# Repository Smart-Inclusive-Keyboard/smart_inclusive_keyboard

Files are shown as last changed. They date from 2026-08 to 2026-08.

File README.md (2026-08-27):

# Smart Inclusive Keyboard

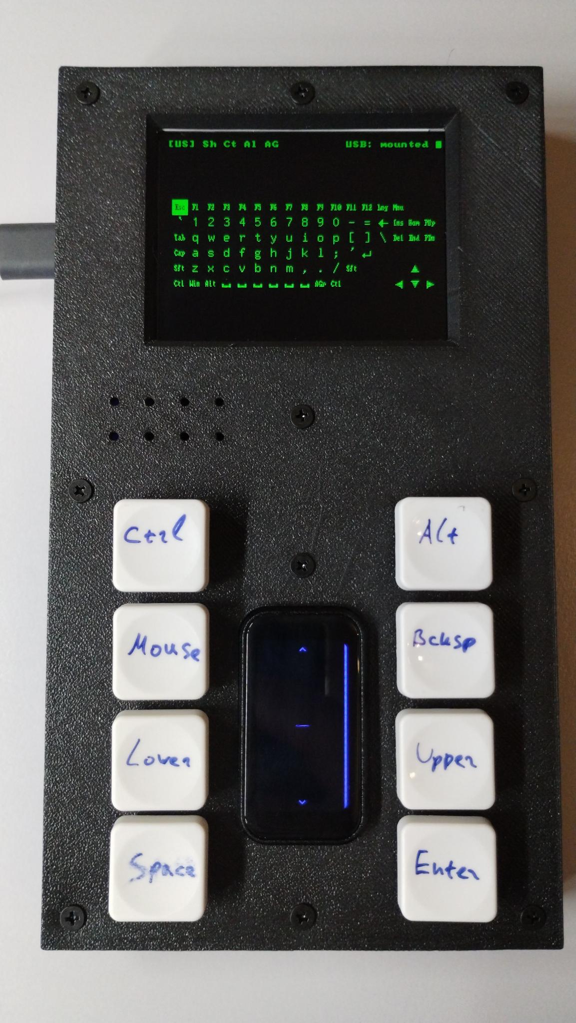
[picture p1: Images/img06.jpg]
Frontal view


This project implements a specialized keyboard for users with limited
hand function, such as those suffering from cerebral palsy.

Theh keyboard consists of 3 ESP32 units connected together:

1. The [main unit](main_unit/) is an ESP32-S3 device with an LCD
display (Freenove FNK0104A), acting as a USB keyboard and mouse
towarrd the PC host. It displays a virtual keyboard on its screen and
allows the user to navigate and select the letters that are to be sent
to the host. The attached speaker pronounces the letters that user is
navigating, so that they don't need to look at the display all the
time. The main unit provides 5v power to the two input controllers
which are connected to it via UART interfaces:

2. The [touch input controller](input_controller), an ESP32-C6 device
with a small touchscreen (Waveshare ESP32-C6-Touch-LCD-1.47). The main
input gesture that it takes from the user is the vertical finger
sliding, allowing to navigate the virtual keyboard vertically or
horizontally. Also, upon a long touch, it switches between vertical
and horizontal modes. An attached vibration motor helps indicating the
mode switch. Also, the "Mouse" button toggles the controller between
keyboard and mouse modes, so that the user can use the same sliding
motions to control the mouse cursor movements vertically or
horizontally.

3. An additional generic ESP32 device (ESP32-C3 Super Mini utilized in
this build) is used for connecting the 7 buttons, as the touch input
device does not have enough free GPIO pins. It uses the same source
code as the touch controller, only without the display and touch
functions.

See also:

1. [Bill of materials](BOM.md)

2. [Photos](Images/)

3. [Demo videos about the project
development](https://www.youtube.com/playlist?list=PLbRMZQ9npKJRurm1_IdCB4-oDc54Ccasw)

## Use of LLM

A large part of the code, especially the keyboard layouts and voice
narrator, are made with the use of Claude AI. As this is a
non-commercial and open source project, the author would never find
enough time to program it by hand.

If anyone finds any copyright infringement in the source code, the
original authors are welcome to contact me and negotiate a satisfying
solution.

## Acknowledgements

The 8x8 font is the [public-domain
font8x8](http://github.com/dhepper/font8x8). The larger 10x20 and
12x16 fonts are derived from
[Greybeard](https://github.com/flowchartsman/greybeard), a vector /
bitmap port of Uwe Waldmann's UW ttyp0 (MIT License).

## Copyright and license

This work is licensed under the MIT License.

Copyright (c) 2026 clackups@gmail.com

Fediverse: [@clackups@social.noleron.com](https://social.noleron.com/@clackups)

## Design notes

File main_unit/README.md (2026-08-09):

# Main unit for the Smart Inclusive Keyboard

ESP-IDF 6.x firmware that implements a virtual keyboard rendered on an
on-board screen, navigated with an external gamepad (receive-only
UART HID link),
that acts as a **HID keyboard + mouse** toward a host computer over
either **Bluetooth LE** (NimBLE) or **USB** (TinyUSB) -- the
transport is a build-time Kconfig choice, gated by what the chosen
ESP32 model actually supports. With PSRAM and a speaker, an
optional narrator speaks each letter as the user navigates.

## Status

The default supported board is the
**Freenove FNK0104A** (2.8" 240x320 ILI9341 SPI panel, NonTouch,
ESP32-S3 with PSRAM, on-board ES8311 codec + speaker). Additional
boards plug in via Kconfig.

## Quick start

```sh
. $IDF_PATH/export.sh
idf.py set-target esp32s3
idf.py menuconfig          # SMART KEYBOARD ->  pick board, layout, theme
idf.py build flash monitor
```

Requires **ESP-IDF v6.0 or newer** (NimBLE host, `esp_lcd`
managed components).

## Architecture

```
main/                  app entry, splash, task wiring
components/
  board/               per-board pin / capability HAL (board.h)
  display/             ILI9341 (SPI) framebuffer + draw API
  fonts/               embedded bitmap fonts (8x16, 16x32)
  theme/               color palette table (default: green on black)
  kb_layout/           keyboard layouts (US default; UA)
  keyboard_ui/         virtual-keyboard state machine + rendering
  gamepad_uart/        receive-only UART HID-report parser
  input_router/        gamepad events -> UI nav + HID dispatch
  hid/                 transport-agnostic HID facade
  ble_hid/             NimBLE composite HID backend (keyboard + mouse)
  usb_hid/             TinyUSB composite HID backend (keyboard + mouse)
  audio/               I2S WAV player (sound output is I2S-only)
  narrator/            letter-name playback (conditional)
docs/
  HARDWARE.md          per-board pinouts + UART gamepad wiring
  CONFIGURATION.md     Kconfig options + NVS overrides
  MULTI_LANG.md        how to add a new keyboard layout
```

Each subsystem is its own IDF component with a small public header
under `include/`. Hardware variants are pure Kconfig choices --
no `#ifdef` ladders outside the `board/` component.

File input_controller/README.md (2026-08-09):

# Input controller for the Smart Inclusive Keyboard

Firmware for the **Waveshare ESP32-C6-Touch-LCD-1.47** development board
that turns the capacitive touch screen into a simple gamepad-style
navigation controller. Touch gestures and dedicated GPIO buttons are
interpreted on-device and streamed as 6-byte HID gamepad reports over a
transmit-only UART to the receiver in the main unit.

A second, display-less board type is also supported for setups that only
need physical buttons (see [Board types](#board-types)).

## Overview

The board polls its AXS5106L capacitive touch controller, classifies the
touch as a long tap or a slide, samples a set of pull-up button GPIOs,
and emits the corresponding gamepad event on UART1. The 1.47" JD9853 LCD
displays a schematic navigation guide and a bright edge line that
indicates the current axis mode.

## Board types

The target board is selected under **Touch Controller -> Hardware board**
in `menuconfig`:

| Board | Display | Touch | Inputs |
|---|---|---|---|
| Waveshare ESP32-C6-Touch-LCD-1.47 | Yes | Yes | Touch gestures, buttons 0-15, mode GPIO, vibration motor |
| Generic ESP32 (no display) | No | No | Buttons 0-15 only |

The **Generic ESP32** board (`CONFIG_TC_BOARD_GENERIC_ESP32`) leaves out
the LCD, capacitive touch, gesture detection and mode GPIO entirely. It
only samples the pull-up button inputs and streams them as game
controller buttons over the transmit-only UART, so it runs on any plain
ESP32-family chip without a display.

## Hardware

Waveshare ESP32-C6-Touch-LCD-1.47 (172x320 portrait IPS):

| Function | Bus | Pins |
|---|-----|---|
| LCD (JD9853) | SPI2 | SCLK=1, MOSI=2, MISO=3, CS=14, DC=15, RST=22, BL=23 |
| Touch (AXS5106L) | I2C0 | SDA=18, SCL=19, INT=21, RST=20 (addr 0x63) |
| Gamepad output | UART1 | TX=7, 115200 8-N-1, transmit-only |
| Vibration motor | GPIO | GPIO4, active high (optional, `CONFIG_TC_HAS_VIBRATION`) |

## Button and mode inputs

Up to sixteen pull-up button inputs (buttons 0-15) plus a mode input (on
touch boards) are configured (defaults below, all configurable in
`menuconfig`). All buttons are unassigned by default; set a button GPIO
to a valid pin to enable it, or to `-1` to leave it unassigned:

| Input | Default GPIO | Action |
|---|---|---|
| Button 0..15 | -1 (unassigned) | Game controller button 0..15 while pulled low |
| Mode | 6 | Select axis output mode (touch boards only) |

Each button GPIO is active low: pulling it to ground reports the
corresponding game controller button as pressed.  A button set to `-1`
is skipped and never reports as pressed.

The **mode** GPIO is an active-low push button that toggles the axis
output mode: each press switches between **impulse** and **continuous**
mode. The button does not need to be held; the controller starts in
impulse mode. The mode GPIO exists only on boards with touch; the
generic board has no mode input.

> Note: all buttons default to unassigned (-1) and the mode GPIO to
> GPIO6; assign button GPIOs and remap the mode GPIO in `menuconfig` to
> free pins as required.

## Gesture mapping

| Gesture | Action |
|---|---|
| Slide up | Negative axis output |
| Slide down | Positive axis output |
| Long tap (>= 500 ms) | Toggle VERTICAL / HORIZONTAL mode |

Short taps are not used; on-screen gamepad buttons come exclusively from
the button GPIOs.

In **VERTICAL** mode the axis output is sent on the Y axis; in
**HORIZONTAL** mode it is sent on the X axis.

### Impulse mode (default)

A slide that spans the full length of the screen produces several axis
events; shorter slides produce proportionally fewer events (always at
least one). The number of events for a full-length slide is configurable
via `CONFIG_TC_SLIDE_FULL_EVENTS` (default 3).

The slide is tracked while the finger is held, so its direction can be
reversed without lifting: sliding up and then back down (or vice versa)
emits impulses in each direction in turn, no release required.

### Continuous mode

When continuous mode is selected, button 9 is held permanently on and
the active axis is set proportional to the sliding finger's distance
from the middle of the touch screen (fully deflected at the edges,
centred at the middle). Releasing the finger returns the axis to centre
while button 9 stays on. The long tap still switches between horizontal
and vertical movement, exactly as in impulse mode.

The finger always slides vertically (up/down); the mode only selects
which axis carries the value, so both VERTICAL and HORIZONTAL modes
respond to the same gesture.

A long tap toggles the mode as soon as `CONFIG_TC_LONG_TAP_MS` elapses
while the finger is still held down -- it does not wait for the finger to
be lifted. Once the toggle has fired, the rest of that touch (including
the eventual release) is ignored. A long tap is only recognized when the
finger stays within `CONFIG_TC_TAP_MAX_MOVE_PX` of the initial touch; if
the finger slides beyond that distance the touch is treated as a slide
and holding it still afterwards will not trigger a tap.

## Mode indicator

The screen shows two arrows and a short centre divider line (about the
width of the arrows). The current mode is shown by a bright line along
one edge of the screen:

- **VERTICAL mode** -- line along the **right** edge.
- **HORIZONTAL mode** -- line along the **top** edge.

All on-screen elements (the arrows, the centre divider and the edge
lines) share a single colour and switch together between an idle and an
active colour. In impulse mode they use `CONFIG_TC_COLOR_IMPULSE_IDLE`
while idle and switch to `CONFIG_TC_COLOR_IMPULSE_ACTIVE` as soon as a
sliding gesture is detected. In continuous mode they use the direction
indicator colour pair: `CONFIG_TC_COLOR_CONTINUOUS_IDLE` (yellow) while
idling and `CONFIG_TC_COLOR_CONTINUOUS_ACTIVE` (orange) while a sliding
gesture is detected.

## Vibration feedback

Boards with a vibration motor (`CONFIG_TC_HAS_VIBRATION`, enabled by
default on the Waveshare ESP32-C6-Touch-LCD-1.47 and driven on GPIO6 by
default) give haptic feedback for the main events:

| Event | Vibration |
|---|---|
| Axis impulse HID report issued | Very short buzz (`TC_VIB_IMPULSE_MS`) |
| Switch to VERTICAL mode | Short buzz (`TC_VIB_VERTICAL_MS`) |
| Switch to HORIZONTAL mode | Slightly longer buzz (`TC_VIB_HORIZONTAL_MS`) |
| Switch to continuous mode | Two long buzzes (`TC_VIB_LONG_MS`, gap `TC_VIB_GAP_MS`) |
| Switch to impulse mode | One long buzz (`TC_VIB_LONG_MS`) |

The motor is driven active high. All pulse durations and the vibration
motor GPIO are configurable in `menuconfig` under **Touch Controller ->
Vibration feedback**. Disable `TC_HAS_VIBRATION` to compile the feature
out entirely.

## UART gamepad report

Every event sends a 6-byte report, as defined in the main unit:

```
byte 0    : buttons 0-7   (bit n = button n pressed)
byte 1    : buttons 8-15  (bit n = button n+8 pressed)
bytes 2-3 : X axis, signed 16-bit little-endian (0 = centre)
bytes 4-5 : Y axis, signed 16-bit little-endian (0 = centre)
```

All 16 button bits are usable: buttons 0-7 occupy byte 0 and buttons
8-15 occupy byte 1.

## Configuration

Tunable options are exposed under **Touch Controller** in `menuconfig`:

| Option | Default | Description |
|---|---|---|
| `TC_HAS_VIBRATION` | y (Waveshare) | Vibration motor present |
| `TC_SCREEN_BRIGHTNESS` | 50 | Backlight brightness (percent) |
| `TC_COLOR_BACKGROUND` | 0x000000 | Background colour (0xRRGGBB) |
| `TC_COLOR_IMPULSE_IDLE` | 0x3333cc | Impulse-mode idle colour (0xRRGGBB) |
| `TC_COLOR_IMPULSE_ACTIVE` | 0x33ccff | Impulse-mode active colour (0xRRGGBB) |
| `TC_COLOR_CONTINUOUS_IDLE` | 0xffff00 | Continuous-mode idle indicator (yellow) |
| `TC_COLOR_CONTINUOUS_ACTIVE` | 0xff8000 | Continuous-mode active indicator (orange) |
| `TC_UART_TX_GPIO` | 7 | UART TX GPIO number |
| `TC_UART_BAUD` | 115200 | UART baud rate |
| `TC_BTN0_GPIO` .. `TC_BTN15_GPIO` | -1 (all unassigned) | Button 0-15 input GPIO numbers (-1 = unassigned) |
| `TC_MODE_GPIO` | 5 | Impulse/continuous mode input GPIO (touch boards) |
| `TC_SLIDE_MIN_PX` | 25 | Minimum travel to classify a slide |
| `TC_TAP_MAX_MOVE_PX` | 15 | Maximum movement for a long tap |
| `TC_LONG_TAP_MS` | 500 | Long-tap threshold (mode toggle) |
| `TC_SLIDE_FULL_EVENTS` | 3 | Axis events for a full-length slide (impulse mode) |
| `TC_VIBRATION_GPIO` | 6 | Vibration motor GPIO (active high) |
| `TC_VIB_IMPULSE_MS` | 15 | Very short buzz on each axis impulse report |
| `TC_VIB_VERTICAL_MS` | 40 | Short buzz on switching to VERTICAL mode |
| `TC_VIB_HORIZONTAL_MS` | 80 | Slightly longer buzz on switching to HORIZONTAL mode |
| `TC_VIB_LONG_MS` | 150 | Long buzz (continuous x2, impulse mode x1) |
| `TC_VIB_GAP_MS` | 80 | Gap between the two continuous-mode buzzes |

## Building and flashing

Requires ESP-IDF 6.0 or newer.

```sh
idf.py set-target esp32c6
idf.py menuconfig      # optional: adjust Touch Controller settings
idf.py build
idf.py -p <PORT> flash monitor
```

Dependencies (`espressif/esp_lcd_touch`, `espressif/esp_lvgl_port`,
`lvgl/lvgl`) are resolved automatically by the IDF component manager.

### Build presets

`CMakePresets.json` defines two configure presets that pair a build
directory with a defaults file:

- `default` -- primary Waveshare ESP32-C6 controller
  (`sdkconfig.defaults`).
- `secondary_esp32c3` -- display-less ESP32-C3 button controller
  (`sdkconfig.defaults.secondary_esp32c3`, generic board with buttons on
  UART TX GPIO10 and buttons 0-6 on GPIO0-7).

Select a preset with, for example, `idf.py -B build/secondary_esp32s3
@CMakePresets.json` or your IDE's CMake preset picker.

## Repository layout

```
main/                  application code (main.c, uart_gamepad.*)
main/Kconfig.projbuild  menuconfig options
components/             board LCD and touch drivers
sdkconfig.defaults      default build configuration (primary C6 board)
sdkconfig.defaults.secondary_esp32s3  defaults for the display-less S3 board
CMakePresets.json       build presets pairing build dirs with defaults
```

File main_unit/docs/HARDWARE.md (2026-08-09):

# Hardware

## Supported boards

### Freenove FNK0104A (2.8" ILI9341, NonTouch) (default)

| Function | GPIO | Notes |
| --- | --- | --- |
| LCD SPI CS | 10 | ILI9341 4-wire SPI panel |
| LCD SPI SCK | 12 | |
| LCD SPI MOSI (D0)  | 11 | data line written to the panel |
| LCD SPI MISO (D1)  | 13 | not required (panel is write-only) |
| LCD DC | 46 | data/command select |
| LCD RST | -1 | tied to module RST; software reset used |
| LCD BL | 45 | active HIGH, LEDC PWM |
| Gamepad 1 UART RX  | 2 | receive-only, 8-N-1, 115200 baud |
| Gamepad 2 UART RX  | 3 | receive-only, 8-N-1, 115200 baud |
| I2S MCLK / BCLK / LRCK / DOUT | 4 / 5 / 7 / 8 | on-board ES8311 codec + speaker |
| Codec I2C SDA / SCL | 16 / 15 | ES8311 codec, addr 0x18 |
| Codec PA enable | 1 | class-D amplifier enable (active-low) |

- ESP32-S3 with PSRAM (`BOARD_HAS_PSRAM`).
- Native panel resolution is 240x320 portrait; the firmware
  presents it as 320x240 landscape. The ILI9341 honours the
  MADCTL row/column-exchange bit, so the landscape rotation is
  done in hardware (no software rotation in the flush path) --
  `board_t::display.swap_xy` stays `false`.
- No touchscreen (NonTouch variant); the firmware does not include
  touchscreen support.
- On-board I2S speaker via ES8311 codec. The board selects
  `BOARD_HAS_SPEAKER` so the narrator is compiled in by default;
  the I2S / codec pins above are hard-coded in
  `components/board/src/board_freenove_fnk0104a.c`.
- The two gamepads are wired to fixed receive-only UART RX pins,
  GPIO 2 (gamepad 1) and GPIO 3 (gamepad 2). These pins are
  hard-coded in the board file (the `CONFIG_SK_GAMEPAD*_UART_RX_GPIO`
  options are ignored for this board); the UART port and baud
  still come from menuconfig.
- If the panel is physically mounted upside-down in its enclosure,
  enable `CONFIG_SK_DISPLAY_ROTATE_180` (Display menu) to flip the
  image 180 degrees at the display-controller level.

### Generic ESP32-S3 / Generic ESP32

Placeholder boards. Edit
`components/board/src/board_generic_s3.c` (or
`board_generic_esp32.c`) to fill in the pin map for your custom
wiring, then select the matching board in menuconfig.

## Gamepad wiring

The external gamepads are separate boards that stream their HID
report into this firmware over a one-way (receive-only) UART
link. Two gamepads are supported; both drive the same on-screen
keyboard. Wire each gamepad's TX line to its configured RX GPIO
(`CONFIG_SK_GAMEPAD1_UART_RX_GPIO` / `CONFIG_SK_GAMEPAD2_UART_RX_GPIO`,
GPIO 2 / 3 by default) and share a common ground. The two
gamepads must use different UART ports. Each link is 8-N-1 at
`CONFIG_SK_GAMEPAD1_UART_BAUD` / `CONFIG_SK_GAMEPAD2_UART_BAUD`
baud (115200 by default); this firmware never transmits. Set a
gamepad's RX GPIO to -1 to disable it.

The report is a fixed 6-byte frame, identical to the HID report
emitted by the companion gamepad firmware
([clackups/esp32s3_dual_foc_gp](https://github.com/clackups/esp32s3_dual_foc_gp)):

```
byte 0:  buttons 0..7  (bit i set = GP_BTN_i pressed)
byte 1:  buttons 8..9  (bits 0..1) + 6 bits padding
byte 2:  X axis, signed 16-bit LE low byte
byte 3:  X axis high byte (-32767..32767, 0 = centred, positive = right)
byte 4:  Y axis, signed 16-bit LE low byte
byte 5:  Y axis high byte (-32767..32767, 0 = centred, positive = down)
```

The firmware refers to gamepad buttons by their zero-based bit
position (`GP_BTN_0`..`GP_BTN_9`) rather than by vendor letter
names (A/B/X/Y or Cross/Circle/Square/Triangle), so the same code
works across controllers whose silkscreens disagree. Bit `i` of
the buttons bitmap triggers `GP_BTN_i`. The `input_router` mapping
is:

- `GP_BTN_0` -> press selected key (or left mouse click in mouse mode)
- `GP_BTN_1` -> Shift + selected key (or right mouse click in mouse mode)
- `GP_BTN_2` -> Space
- `GP_BTN_3` -> Enter
- `GP_BTN_4` -> Backspace
- `GP_BTN_5` -> Ctrl + selected key (like GP_BTN_0 with Ctrl held)
- `GP_BTN_6` -> AltGr + selected key (like GP_BTN_0 with right Alt held)
- `GP_BTN_7` -> unused
- `GP_BTN_8` -> unused
- `GP_BTN_9` -> on down: keyboard mode; on up: mouse mode

Sticky modifiers (Shift / Ctrl / Alt / AltGr) stay engaged until
the next character key is pressed. The keyboard layout is changed
with the on-screen **Lng** key and the colour theme / enabled
languages from the **Mnu** settings menu (both on the function-key
row, right of F12).

### UART transport

The driver installs the UART in receive-only mode (no TX / RTS /
CTS pin is driven) and reads one 6-byte frame at a time. The
analog axes are reduced to discrete D-pad directions using
`CONFIG_SK_GAMEPAD_AXIS_DEADZONE`. To adapt the wire format, edit
`gamepad_parse_report()` in
`components/gamepad_uart/src/gamepad_uart.c`.

## Power

The Freenove FNK0104A is USB-powered (5 V). `CONFIG_BOARD_HAS_BATTERY`
is not yet selected for any shipping board -- when it is,
`board_t.battery_adc_channel` gates the on-screen battery indicator.

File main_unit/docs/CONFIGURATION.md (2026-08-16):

# Configuration

All build-time options live under
**SMART KEYBOARD** in `idf.py menuconfig`.

## Board selection

`SK_BOARD_*` -- exactly one. The default is
`SK_BOARD_FREENOVE_FNK0104A` (Freenove 2.8" ILI9341, NonTouch).
Selecting a board automatically
"selects" the capability symbols that gate optional components:

| Symbol | Meaning |
| --- | --- |
| `BOARD_HAS_PSRAM` | Component code may allocate from PSRAM |
| `BOARD_HAS_DISPLAY` | Some panel driver is configured |
| `BOARD_HAS_DISPLAY_ILI9341`  | Build the ILI9341 SPI backend |
| `BOARD_HAS_SPEAKER` | I2S DAC wired -> compile in audio + |
| | narrator |
| `BOARD_HAS_BATTERY` | VBAT exposed -> battery indicator |

The Audio / Narrator menu is **hidden** unless `BOARD_HAS_PSRAM`
and `BOARD_HAS_SPEAKER` are both set, because narration requires
both to be useful.

## Display

`SK_DISPLAY_BACKLIGHT_PERCENT` (0..100) sets the panel backlight
brightness applied at boot, as a percentage of full brightness.
Boards with a controllable (LEDC PWM) backlight honour it; boards
without one ignore it. The default is tuned per board: 50% for the
Freenove FNK0104A.

`SK_DISPLAY_ROTATE_180` flips the panel image 180 degrees (both
axes mirrored) at the display-controller level. Useful when the
panel is physically mounted upside-down in its enclosure, e.g. the
Freenove FNK0104A.

## Gamepad transport

The external gamepads are separate boards that stream their HID
report into this firmware over a one-way (receive-only) UART
link (8-N-1). This firmware never transmits. Two gamepads are
supported; both feed the same `gamepad_event_t` queue and drive
the same on-screen keyboard. The 6-byte report format and queue
feed a transport-agnostic `input_router`.

| Option | Default | Range |
| --- | --- | --- |
| `SK_GAMEPAD_AXIS_DEADZONE` | 8000 | 0..32767 |
| `SK_GAMEPAD1_UART_PORT` | 1 | 1..2 (UART1 / UART2) |
| `SK_GAMEPAD1_UART_RX_GPIO` | 21 | any GPIO, -1 = off |
| `SK_GAMEPAD1_UART_BAUD` | 115200  | any baud rate |
| `SK_GAMEPAD2_UART_PORT` | 2 | 1..2 (UART1 / UART2) |
| `SK_GAMEPAD2_UART_RX_GPIO` | 38 | any GPIO, -1 = off |
| `SK_GAMEPAD2_UART_BAUD` | 115200  | any baud rate |

Each RX pin is connected to a gamepad's TX line; no TX / RTS /
CTS pin is driven. The two gamepads must use different UART ports.
Set a gamepad's `*_UART_RX_GPIO` to -1 to disable it.

> **Note:** On the Freenove FNK0104A board the gamepad RX pins are
> hard-coded to GPIO 2 (gamepad 1) and GPIO 3 (gamepad 2) in the
> board file, so the `SK_GAMEPAD*_UART_RX_GPIO` options above have
> no effect for that board. The UART port and baud options still
> apply.
`SK_GAMEPAD_AXIS_DEADZONE` is shared by both gamepads and applied
to the signed 16-bit analog axes carried in the report. See
[HARDWARE.md](HARDWARE.md) for the wire format and button map.

## HID transport

The firmware acts as a HID peripheral over either Bluetooth LE or
USB. The transport is selected at build time via
`SK_HID_TRANSPORT`; each option is only offered when the target
SoC actually has the corresponding controller
(`SOC_BLE_SUPPORTED` / `SOC_USB_OTG_SUPPORTED`).

| Option | Targets | Backend |
| --- | --- | --- |
| `SK_HID_TRANSPORT_BLE`  | classic ESP32, S3 | NimBLE GATT HID |
| `SK_HID_TRANSPORT_USB`  | ESP32-S2, S3, P4  | TinyUSB composite HID |

The classic ESP32 only exposes the BLE option; ESP32-S2 only the
USB option; ESP32-S3 lets you pick either.

## BLE HID

Only visible when `SK_HID_TRANSPORT_BLE` is selected.

| Option | Default | Purpose |
| --- | --- | --- |
| `SK_BLE_DEVICE_NAME` | `SmartKeyboard`| advertised local name |
| `SK_BLE_MANUFACTURER` | `clackups` | shown in some host UIs |
| `SK_BLE_BOND_ON_PAIR` | y | persist bonds to NVS |

## USB HID

Only visible when `SK_HID_TRANSPORT_USB` is selected.

| Option | Default | Purpose |
| --- | --- | --- |
| `SK_USB_MANUFACTURER` | `clackups` | USB iManufacturer string |
| `SK_USB_PRODUCT` | `SmartKeyboard`| USB iProduct string |
| `SK_USB_SERIAL` | `000001` | USB iSerial string |

When building a pure-USB image you can also disable the Bluetooth
stack in `menuconfig > Component config > Bluetooth` to reclaim
the ~60 KB it occupies in flash + ~30 KB in RAM.

## Keyboard layout

`SK_LAYOUT_DEFAULT` is the compile-time default. The active layout
is **not** persisted to NVS: the device always boots with the first
*available* (Kconfig-activated) language. The active layout is
bound to the on-screen **Lng** key (right of F12), which rotates
through the *enabled* languages only (see the settings menu below).
Both US and Ukrainian (UA) are full layouts. The Ukrainian layout
renders the real Cyrillic letters on the keys (upper-cased while
Shift is held), using the Cyrillic glyphs embedded in the 10x20 UI
font.

### Enabled languages

The **Enabled languages** Kconfig switches decide which layouts are
*available* on the device. Only available layouts are offered in the
settings menu and take part in the Lng rotation:

| Option | Default | Layout |
| --- | --- | --- |
| `SK_LANG_ENABLE_US` | y | US English |
| `SK_LANG_ENABLE_UA` | y | Ukrainian (UA) |

Layouts not activated here never appear in the settings menu. The
enabled set among the available layouts can be changed at runtime
from the settings menu, but is not persisted across reboots.
`SK_LANG_ENABLE_UA` also controls whether the Ukrainian narrator
clips (`wav/ua_*.wav`) are embedded into the firmware image.

### Host layout-switch hotkey

When the device's active layout changes, the firmware emits
`Ctrl+Shift+<digit>` so a host configured with matching
input-language hotkeys switches along with it. Each language's
digit is configurable under **Host layout-switch hotkey**; `0`
disables the report for that language:

| Option | Default | Sends |
| --- | --- | --- |
| `SK_LAYOUT_SWITCH_DIGIT_US` | 1 | Ctrl+Shift+1 |
| `SK_LAYOUT_SWITCH_DIGIT_UA` | 4 | Ctrl+Shift+4 |

## Theme

Same model as the layout: a Kconfig default that can be changed
at runtime from the settings menu (`keyboard_ui_cycle_theme()`).
Five built-ins ship: `green_on_black` (default),
`darkgreen_on_black`, `white_on_black`, `black_on_white`,
`default`.

## Settings menu

The on-screen **Mnu** key (right of F12) opens a modal,
gamepad-navigated settings menu. While it is open the keyboard is
replaced by the menu and the gamepad routes here: Up/Down move the
selection, Left/Right change the highlighted value, and the action
button (`GP_BTN_0`) activates it. The menu lets the user pick the
colour theme, set the **mouse pointer speed** (7 levels, slow to
fast), toggle **navigation rollover** and toggle which of the
*available* (Kconfig-activated) languages take part in the Lng
rotation. Languages not activated in Kconfig are not listed. At
least one language is always enabled and the active language can
never be disabled. Theme, mouse-speed and navigation-rollover
choices persist to NVS; the language selection does not.

Navigation rollover (`Nav rollover: ON/off`, default **off**)
controls what happens when the selection cursor is moved past the
edge of the on-screen key grid. When disabled (the default), the
cursor clamps at the edge row/column. When enabled, moving past an
edge wraps the selection around to the opposite edge in that same
axis (e.g. moving up from the top row selects the bottom row of the
same column).

## Gamepad buttons

The external gamepad's numbered buttons map to fixed actions
(`components/input_router`):

| Button | Keyboard mode | Mouse mode |
| --- | --- | --- |
| `GP_BTN_0` | press selected key | left click |
| `GP_BTN_1` | Shift + selected key | right click |
| `GP_BTN_2` | Space | Space |
| `GP_BTN_3` | Enter | Enter |
| `GP_BTN_4` | Backspace | Backspace |
| `GP_BTN_5` | Ctrl + selected key | left click |
| `GP_BTN_6` | AltGr + selected key | left click |
| `GP_BTN_7` | unused | unused |
| `GP_BTN_8` | unused | unused |
| `GP_BTN_9` | down: mouse mode; up: keyboard mode |

The D-pad / analog stick moves the selection cursor (keyboard
mode) or the menu selection (settings menu). In **mouse mode** the
analog axes drive the pointer **proportionally**: the further the
stick is pushed past the dead-zone, the faster the pointer moves,
scaled by the Mouse-speed level chosen in the settings menu.
`GP_BTN_5` / `GP_BTN_6` act like `GP_BTN_0` but momentarily
hold Ctrl / AltGr for that single keypress. Shift / Ctrl / Alt /
AltGr toggled via the on-screen modifier keys are **sticky**: they
hold the modifier until the next character key is pressed.

## Audio / narrator (conditional)

| Option | Default | Purpose |
| --- | --- | --- |
| `NARRATOR_ENABLE` | y | speak each key as it is sent |
| `AUDIO_I2S_PORT` | 0 | I2S port (0 or 1) |
| `AUDIO_I2S_BCLK_GPIO` | 5 | |
| `AUDIO_I2S_LRCK_GPIO` | 6 | |
| `AUDIO_I2S_DOUT_GPIO` | 7 | |
| `AUDIO_VOLUME` | 70 | 0..100, applied digitally |

The narrator pronounces the letter or symbol that a gamepad
action sends, taking the current Shift state into account. The
Ukrainian layout ships its own clip set so the spoken name matches
the Cyrillic character the host receives, not the ASCII
transliteration drawn on screen.

Sound output is **always** I2S -- there is no PWM / internal-DAC
fallback. On boards without `BOARD_HAS_SPEAKER` selected the
audio + narrator components compile to no-op stubs so calls from
`input_router` are free.

## NVS overrides

Runtime preferences live under the `sk_ui` NVS namespace:

| Key | Type | Set by |
| --- | ---- | --- |
| `theme` | str  | `keyboard_ui_cycle_theme()` |

The active language and the enabled-language set are intentionally
not persisted: the device always boots with the first available
(Kconfig-activated) layout.

To reset to the Kconfig defaults, erase the namespace from a
serial console or wipe NVS with `idf.py erase-flash`.

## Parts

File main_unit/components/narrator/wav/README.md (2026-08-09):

# Narrator assets

This directory holds WAV files embedded into the firmware at
build time via `EMBED_FILES` (see
`components/narrator/CMakeLists.txt`). The narrator component is
**only** compiled in when the selected board has both PSRAM and
a speaker and `CONFIG_NARRATOR_ENABLE` is set; otherwise the
embed list is skipped entirely.

## Where do the WAVs come from?

They are taken verbatim from the upstream
[clackups/smart-keyboard](https://github.com/clackups/smart-keyboard)
project's `audio/` folder (MIT-licensed, same as this firmware).
The letter / digit clips are the US-English set
(`us_<letter>.wav` / `us_<digit>.wav` upstream), renamed to drop
the `us_` prefix so they match the symbol names the narrator
declares. `esc.wav` upstream is imported as `escape.wav`. The
narrator expects the following filenames:

```
a.wav, b.wav, ..., z.wav
0.wav, 1.wav, ..., 9.wav
space.wav, enter.wav, backspace.wav, tab.wav, escape.wav
shift.wav, ctrl.wav, alt.wav, altgr.wav, capslock.wav
apostrophe.wav, backslash.wav, backtick.wav, comma.wav,
equals.wav, lbracket.wav, minus.wav, period.wav,
rbracket.wav, semicolon.wav, slash.wav
f1.wav .. f12.wav
insert.wav, home.wav, pageup.wav,
delete.wav, end.wav, pagedown.wav,
up.wav, down.wav, left.wav, right.wav
```

Every cell of the on-screen US layout has a matching clip
except the "Win" / "Cmd" modifier (no upstream recording);
that key narrates as silence.

### Shifted number-row symbols

The number row's Shift glyphs (`~ ! @ # $ % ^ & * ( ) _ +`) are
not separate HID usages -- Shift+1 still sends
`HID_USAGE_1`, only the host-side glyph changes -- so the
narrator can't derive their spoken name from the HID usage
alone. `layout_us.c` names an explicit narrator clip token per
key (see the `KSH` macro) for the following language-neutral
clips, spoken in place of the unshifted digit / mark while
Shift is held:

```
tilde.wav, exclamation.wav, at.wav, hash.wav, dollar.wav,
percent.wav, caret.wav, ampersand.wav, asterisk.wav,
lparen.wav, rparen.wav, underscore.wav, plus.wav
```

These were synthesized with `espeak-ng` (`espeak-ng -v en-us -s
150 -w <name>.wav "<word>"`) at the same PCM16/22050Hz mono
format as the rest of the pack; replace with recordings from the
upstream pack if/when it adds them.

## Format

Standard RIFF/WAVE, **PCM 16-bit mono, 22050 Hz**. The I2S
driver re-clocks to the file's reported sample rate, so other
rates work too, but 22050 / 16-bit is what the upstream pack
uses and what the audio buffer sizes in `components/audio/` are
tuned for.

## License

MIT, inherited from the upstream project. See its `LICENSE`
file for the exact text.

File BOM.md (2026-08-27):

# Smart Inclusive Keyboard - Bill of materials

Electronic components:

1. 1pc [Freenove FNK0104A
board](https://docs.freenove.com/projects/fnk0104/en/latest/fnk0104/codes/MAIN/Freenove_ESP32S3_Display.html)
(2.8" LCD, no touch, with speaker)

2. 1pc [Waveshare ESP32-C6-Touch-LCD-1.47](https://docs.waveshare.com/ESP32-C6-Touch-LCD-1.47)

3. 1pc [ESP32-C3 Super Mini](https://www.espboards.dev/esp32/esp32-c3-super-mini/)

4. 1pc [Vibration Motor
Module](https://easyelecmodule.com/vibration-motor-module/)

Assembly:

1. Top cover: 10pc [M2.5 x 12mm Hexagonal Male/Female Standoffs](https://www.vital-parts.co.uk/threaded-hex-standoffs-male-female/11245-hmf-m25-12-s5-npb), 10pc M3.5 x 5mmPhillips Ultra Thin Flat Head Screws, 10pc M2.5 nuts.

2. Freenove FNK0104A: 4pc M3 x 6mm Hexagonal Female/Female Standoffs, 4pc M3 x5mm screws, 4pc M3 x 6mm screws.

3. The speaker has an adhesive surface and sticks to the bottom plate.

4. Waveshare ESP32-C6-Touch-LCD-1.47: 4pc M2 x 8mm Male/Female Standoffs, 4pc M2 x 6mm screws.

5. Vibration Motor: 2pc M3 x 10mm screws, 2pc M3 nuts.

Other components:

1. 8pc low-profile MX keyboard switchhes

2. 8pc low-profile keycaps

3. 5pc 12x6mm self-adhesive silicone bumpers

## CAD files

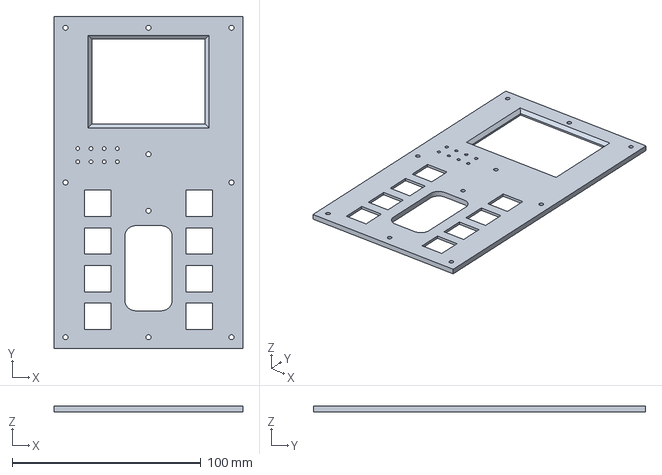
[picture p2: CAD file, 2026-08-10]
3D_Prints/body_top-Body.3mf
100.0 x 176.0 x 3.00 mm

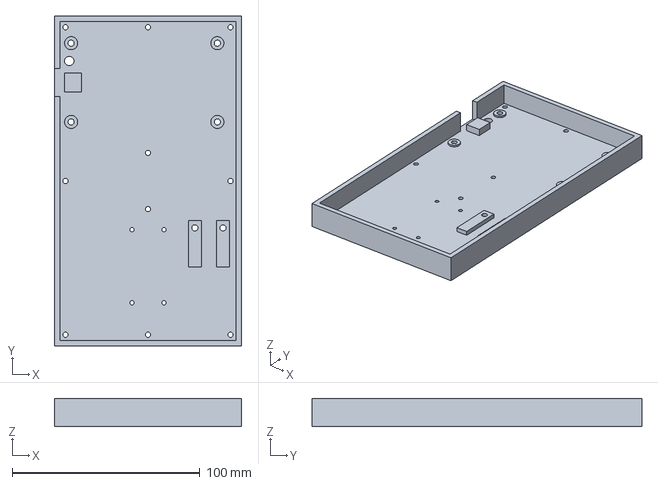
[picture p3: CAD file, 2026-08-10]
3D_Prints/body_bottom-Body.3mf
100.0 x 176.0 x 15.0 mm

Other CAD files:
3D_Prints/body_bottom.FCStd
3D_Prints/body_top.FCStd

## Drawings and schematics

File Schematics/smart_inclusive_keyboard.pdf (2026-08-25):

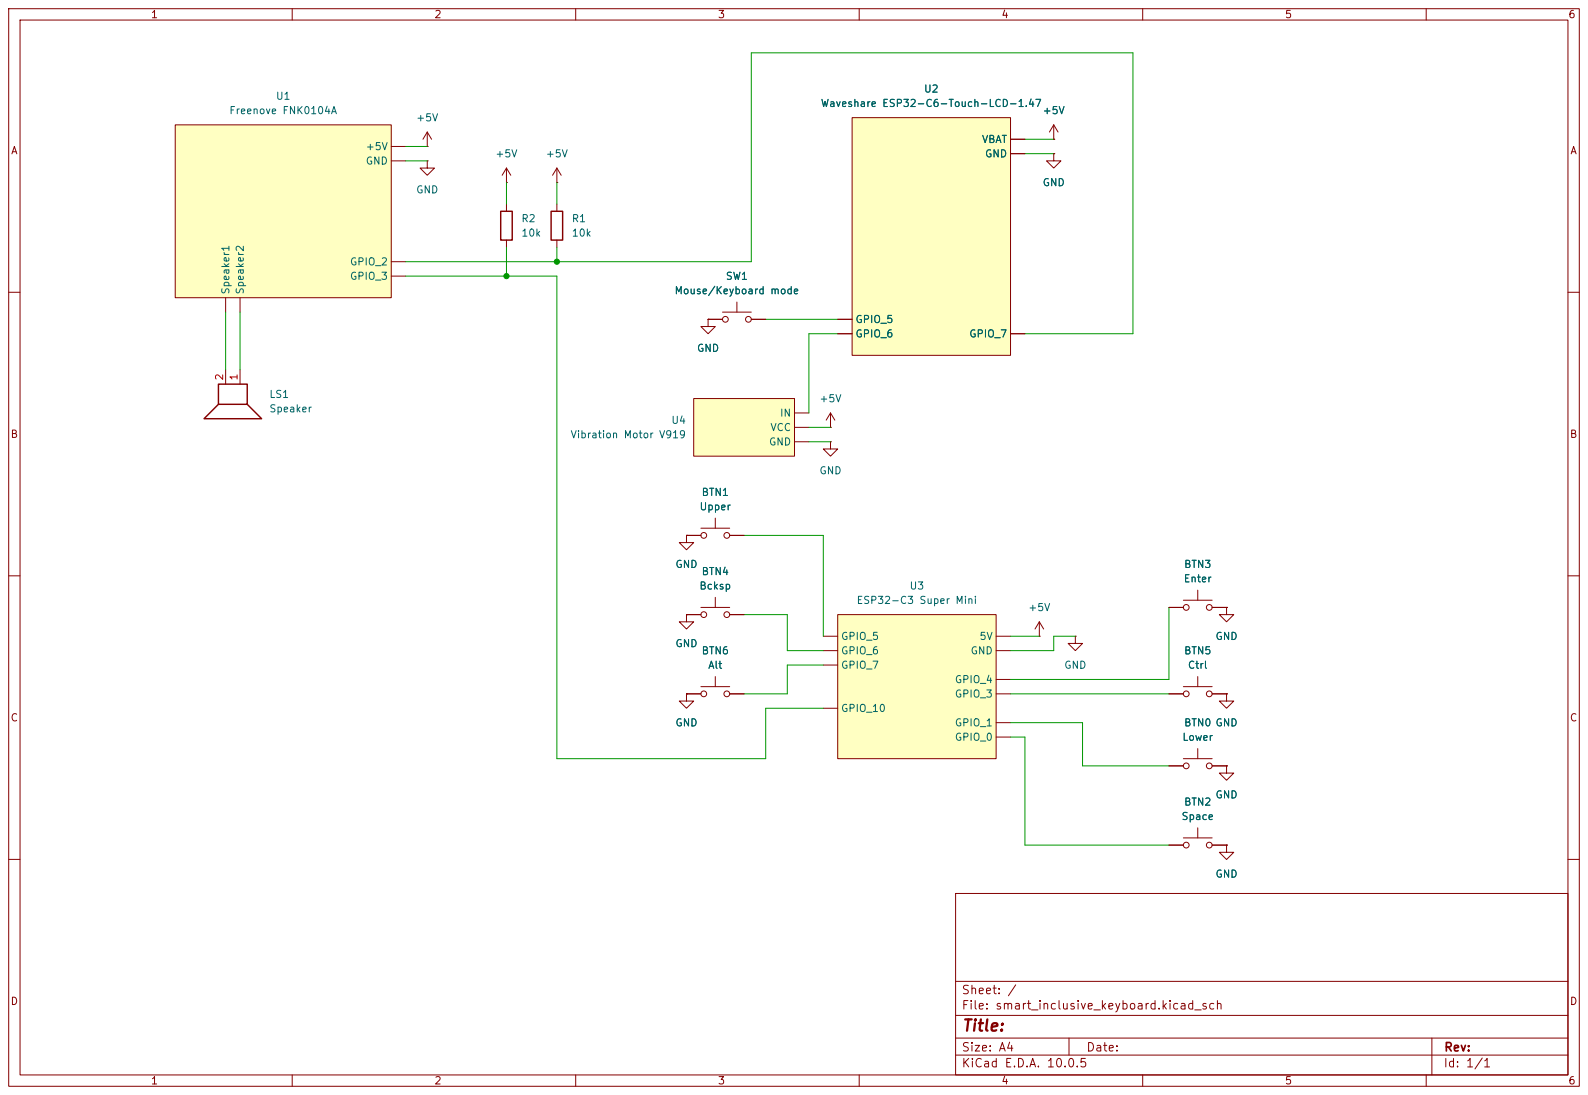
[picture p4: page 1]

GPIO_7 U2 Waveshare ESP32-C6-Touch-LCD-1.47 BTN4 Bcksp GND

Enter GND +5V U2 Waveshare ESP32-C6-Touch-LCD-1.47 GPIO_5 GPIO_6

Size: A4 | Rev:
KiCad E.D.A. 10.0.5 | Id: 1/1

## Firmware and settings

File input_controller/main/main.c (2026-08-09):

/*
 * main.c -- ESP32 Touch Controller
 *
 * Reads capacitive touch from an AXS5106L controller, interprets the
 * gestures, and sends 6-byte HID gamepad reports over a transmit-only
 * UART to an esp32s3_smart_keyboard receiver.
 *
 * Two board types are supported, selected in menuconfig:
 *   - Waveshare ESP32-C6-Touch-LCD-1.47 (display + touch, described
 *     below).  Selects CONFIG_TC_HAS_DISPLAY and CONFIG_TC_HAS_TOUCH.
 *   - Generic ESP32 (CONFIG_TC_BOARD_GENERIC_ESP32): no display and no
 *     touch; only the pull-up button inputs and the UART gamepad output
 *     are built.  Neither capability flag is set, so all LCD/touch and
 *     gesture code below is compiled out.
 *
 * Hardware (Waveshare ESP32-C6-Touch-LCD-1.47, verified):
 *   LCD  JD9853  SPI2   SCLK=1 MOSI=2 MISO=3  CS=14 DC=15 RST=22 BL=23
 *                172x320 portrait, column gap=34, colour-inversion on
 *   Touch AXS5106L  I2C0  SDA=18 SCL=19 INT=21 RST=20  addr=0x63
 *   UART  TX=GPIO7  115200 8-N-1  (gamepad HID output)
 *   Vibration motor  GPIO4  (active high, CONFIG_TC_HAS_VIBRATION)
 *
 * Button/mode inputs (configurable, pull-up, active low):
 *   GPIO for buttons 0-15  generate game controller buttons 0-15
 *   Mode GPIO              each press toggles impulse <-> continuous mode
 *                          (touch boards only)
 *
 * Optional vibration feedback (CONFIG_TC_HAS_VIBRATION) pulses a motor
 * GPIO to acknowledge events: a very short buzz on every axis impulse HID
 * report, a short buzz on switching to VERTICAL and a slightly longer one
 * on switching to HORIZONTAL, two long buzzes on switching to continuous
 * mode and one long buzz on switching to impulse mode.  All durations are
 * configurable (see Kconfig).
 *
 * Gesture -> HID mapping
 *   Slide up        negative axis impulse (impulse mode) or proportional
 *                   axis (continuous mode)
 *   Slide down      positive axis impulse (impulse mode) or proportional
 *                   axis (continuous mode)
 *   Long tap (>=TC_LONG_TAP_MS) toggle VERTICAL / HORIZONTAL mode
 *                          (fires as soon as the threshold elapses,
 *                          without waiting for the finger to lift)
 *
 * In impulse mode a slide spanning the full length of the screen emits
 * several axis impulse events (CONFIG_TC_SLIDE_FULL_EVENTS, default 3);
 * shorter slides emit proportionally fewer events.  The slide is tracked
 * while the finger is held, so its direction can be reversed without
 * lifting: turning back on the slide emits impulses in the new direction.
 *
 * The finger always slides vertically (up/down).  In continuous mode
 * button 9 is held permanently on and the active axis is set proportional
 * to the sliding finger's distance from the middle of the touch screen;
 * the long tap switches the active axis just as in impulse mode.  Both
 * VERTICAL and HORIZONTAL modes react to the same up/down gesture.
 *
 * In VERTICAL mode the axis output is sent on the Y axis; in HORIZONTAL
 * mode it is sent on the X axis.
 *
 * The screen shows a schematic navigation guide with two arrows and a
 * short centre divider line.  The current mode is indicated by a bright
 * edge line: along the right edge in VERTICAL mode and along the top edge
 * in HORIZONTAL mode.  All on-screen elements (arrows, divider and edge
 * lines) share one colour and switch together between an idle and an
 * active colour: in impulse mode the idle CONFIG_TC_COLOR_IMPULSE_IDLE
 * and the active CONFIG_TC_COLOR_IMPULSE_ACTIVE (applied as soon as a
 * slide is detected), and in continuous mode the indicator colour pair
 * (idle CONFIG_TC_COLOR_CONTINUOUS_IDLE, active
 * CONFIG_TC_COLOR_CONTINUOUS_ACTIVE).  Backlight brightness and the
 * interface colours are configurable (see Kconfig).
 */

#include <string.h>
#include <stdio.h>
#include "freertos/FreeRTOS.h"
#include "freertos/task.h"
#include "freertos/queue.h"
#include "esp_log.h"
#include "esp_timer.h"
#include "esp_err.h"
#include "driver/gpio.h"

#include "sdkconfig.h"

#if CONFIG_TC_HAS_DISPLAY
#include "driver/spi_master.h"
#include "driver/ledc.h"

#include "esp_lcd_panel_io.h"
#include "esp_lcd_panel_vendor.h"
#include "esp_lcd_panel_ops.h"
#include "esp_lcd_jd9853.h"

#include "esp_lvgl_port.h"
#include "lvgl.h"
#endif /* CONFIG_TC_HAS_DISPLAY */

#if CONFIG_TC_HAS_TOUCH
#include "driver/i2c_master.h"

#include "esp_lcd_touch.h"
#include "esp_lcd_touch_axs5106.h"
#endif /* CONFIG_TC_HAS_TOUCH */

#include "uart_gamepad.h"

static const char *TAG = "tc";

/* ---------------------------------------------------------------------
 * Board-specific pin definitions
 * --------------------------------------------------------------------- */
#ifdef CONFIG_TC_BOARD_WAVESHARE_C6_TOUCH_LCD_147

/* LCD SPI (SPI2) */
#define LCD_SCLK         GPIO_NUM_1
#define LCD_MOSI         GPIO_NUM_2
#define LCD_MISO         GPIO_NUM_3
#define LCD_CS           GPIO_NUM_14
#define LCD_DC           GPIO_NUM_15
#define LCD_RST          GPIO_NUM_22
#define LCD_BL           GPIO_NUM_23
#define LCD_PIXEL_CLK_HZ (80 * 1000 * 1000)
#define LCD_H_RES        172
#define LCD_V_RES        320
#define LCD_COL_GAP      34   /* JD9853 x-offset at rotation 0 */

/* Touch I2C (I2C0) */
#define TP_SDA           GPIO_NUM_18
#define TP_SCL           GPIO_NUM_19
#define TP_INT           GPIO_NUM_21
#define TP_RST           GPIO_NUM_20

/* Backlight PWM */
#define BL_LEDC_TIMER    LEDC_TIMER_0
#define BL_LEDC_MODE     LEDC_LOW_SPEED_MODE
#define BL_LEDC_CH       LEDC_CHANNEL_0
#define BL_LEDC_DUTY_RES LEDC_TIMER_10_BIT
#define BL_LEDC_FREQ_HZ  5000

#endif /* CONFIG_TC_BOARD_WAVESHARE_C6_TOUCH_LCD_147 */

/* ---------------------------------------------------------------------
 * Application constants
 * --------------------------------------------------------------------- */
#define INPUT_POLL_MS   20    /* button / touch polling interval      */

/* Button input GPIOs (pull-up, active low, from Kconfig). */
#define BTN_GPIO_COUNT  16

/* Button index that is held on permanently while in continuous mode. */
#define CONTINUOUS_BTN  9

#if CONFIG_TC_HAS_DISPLAY
#define DRAW_BUF_LINES  50    /* LVGL DMA draw buffer height in lines */

/* Interface colours (24-bit 0xRRGGBB, from Kconfig). */
#define COLOR_BG        lv_color_hex(CONFIG_TC_COLOR_BACKGROUND)
#define COLOR_FG        lv_color_hex(CONFIG_TC_COLOR_IMPULSE_IDLE)
#define COLOR_HL        lv_color_hex(CONFIG_TC_COLOR_IMPULSE_ACTIVE)
#define COLOR_CONT_IDLE   lv_color_hex(CONFIG_TC_COLOR_CONTINUOUS_IDLE)
#define COLOR_CONT_ACTIVE lv_color_hex(CONFIG_TC_COLOR_CONTINUOUS_ACTIVE)

/* vertical/horizontal indicator line along the edge */
#define EDGE_INDICATOR_THICKNESS 4

/* Width of the short centre divider line -- approximately the width of
 * the up/down arrow glyphs it sits between. */
#define DIVIDER_WIDTH   24
#endif /* CONFIG_TC_HAS_DISPLAY */

#if CONFIG_TC_HAS_TOUCH
#define IMPULSE_MS      100   /* axis impulse duration                */

#define SLIDE_MIN_PX    CONFIG_TC_SLIDE_MIN_PX
#define TAP_MAX_MOVE_PX CONFIG_TC_TAP_MAX_MOVE_PX
#define LONG_TAP_MS     CONFIG_TC_LONG_TAP_MS
#define SLIDE_FULL_EVENTS CONFIG_TC_SLIDE_FULL_EVENTS

#define MODE_GPIO       CONFIG_TC_MODE_GPIO
#endif /* CONFIG_TC_HAS_TOUCH */

#if CONFIG_TC_HAS_VIBRATION
/* Vibration motor GPIO (active high) and feedback pulse durations. */
#define VIB_GPIO          CONFIG_TC_VIBRATION_GPIO
#define VIB_IMPULSE_MS    CONFIG_TC_VIB_IMPULSE_MS    /* very short */
#define VIB_VERTICAL_MS   CONFIG_TC_VIB_VERTICAL_MS   /* short      */
#define VIB_HORIZONTAL_MS CONFIG_TC_VIB_HORIZONTAL_MS /* longer     */
#define VIB_LONG_MS       CONFIG_TC_VIB_LONG_MS       /* long       */
#define VIB_GAP_MS        CONFIG_TC_VIB_GAP_MS        /* pulse gap  */
#else
/* Fallback durations so the vibration_trigger() no-op call sites compile
 * unchanged when no vibration motor is present. */
#define VIB_IMPULSE_MS    0
#define VIB_VERTICAL_MS   0
#define VIB_HORIZONTAL_MS 0
#define VIB_LONG_MS       0
#define VIB_GAP_MS        0
#endif /* CONFIG_TC_HAS_VIBRATION */

typedef enum {
    MODE_VERTICAL,
    MODE_HORIZONTAL,
} tc_mode_t;

/* Axis output mode, selected by the mode GPIO. */
typedef enum {
    OUTPUT_IMPULSE,
    OUTPUT_CONTINUOUS,
} tc_output_mode_t;

/* ---------------------------------------------------------------------
 * Module-level state
 * --------------------------------------------------------------------- */
#if CONFIG_TC_HAS_DISPLAY
static esp_lcd_panel_io_handle_t s_io_handle;
static esp_lcd_panel_handle_t    s_panel;
static lv_disp_t                *s_disp;
static lv_obj_t                 *s_line_right;  /* shown in VERTICAL mode   */
static lv_obj_t                 *s_line_top;    /* shown in HORIZONTAL mode */
static lv_obj_t                 *s_lbl_up;      /* up arrow                 */
static lv_obj_t                 *s_lbl_dn;      /* down arrow               */
static lv_obj_t                 *s_divider;     /* short centre line        */

/* Backlight PWM full-scale duty (2^BL_LEDC_DUTY_RES - 1), computed once
 * in hw_lcd_init(), used to scale a 0..100 percent request. */
static uint32_t s_bl_max_duty;
#endif /* CONFIG_TC_HAS_DISPLAY */
#if CONFIG_TC_HAS_TOUCH
static esp_lcd_touch_handle_t    s_touch;
#endif /* CONFIG_TC_HAS_TOUCH */
#if CONFIG_TC_HAS_DISPLAY || CONFIG_TC_HAS_TOUCH
static volatile tc_mode_t        s_mode = MODE_VERTICAL;
#endif
static volatile tc_output_mode_t s_output_mode = OUTPUT_IMPULSE;

/* Button GPIOs (buttons 0-15; -1 = unassigned). */
static const int s_btn_gpios[BTN_GPIO_COUNT] = {
    CONFIG_TC_BTN0_GPIO,  CONFIG_TC_BTN1_GPIO,  CONFIG_TC_BTN2_GPIO,
    CONFIG_TC_BTN3_GPIO,  CONFIG_TC_BTN4_GPIO,  CONFIG_TC_BTN5_GPIO,
    CONFIG_TC_BTN6_GPIO,  CONFIG_TC_BTN7_GPIO,  CONFIG_TC_BTN8_GPIO,
    CONFIG_TC_BTN9_GPIO,  CONFIG_TC_BTN10_GPIO, CONFIG_TC_BTN11_GPIO,
    CONFIG_TC_BTN12_GPIO, CONFIG_TC_BTN13_GPIO, CONFIG_TC_BTN14_GPIO,
    CONFIG_TC_BTN15_GPIO,
};

/* Latest button bitmask read from the button GPIOs (buttons 0-15). */
static volatile uint16_t s_gpio_buttons;

/* Latest axis values pushed to the gamepad report. */
static volatile int16_t s_axis_x;
static volatile int16_t s_axis_y;

/* ---------------------------------------------------------------------
 * Hardware initialisation
 * --------------------------------------------------------------------- */
#if CONFIG_TC_HAS_DISPLAY
static void hw_lcd_init(void)
{
    /* SPI bus */
    const spi_bus_config_t buscfg = {
        .sclk_io_num     = LCD_SCLK,
        .mosi_io_num     = LCD_MOSI,
        .miso_io_num     = LCD_MISO,
        .quadhd_io_num   = -1,
        .quadwp_io_num   = -1,
        .max_transfer_sz = LCD_H_RES * DRAW_BUF_LINES * sizeof(uint16_t),
    };
    ESP_ERROR_CHECK(spi_bus_initialize(SPI2_HOST, &buscfg, SPI_DMA_CH_AUTO));

    /* Panel IO */
    esp_lcd_panel_io_spi_config_t io_cfg =
        JD9853_PANEL_IO_SPI_CONFIG(LCD_CS, LCD_DC, NULL, NULL);
    io_cfg.pclk_hz = LCD_PIXEL_CLK_HZ;
    ESP_ERROR_CHECK(esp_lcd_new_panel_io_spi(
        (esp_lcd_spi_bus_handle_t)SPI2_HOST, &io_cfg, &s_io_handle));

    /* Panel */
    const esp_lcd_panel_dev_config_t panel_cfg = {
        .reset_gpio_num = LCD_RST,
        .rgb_ele_order  = LCD_RGB_ELEMENT_ORDER_RGB,
        .bits_per_pixel = 16,
    };
    ESP_ERROR_CHECK(esp_lcd_new_panel_jd9853(s_io_handle, &panel_cfg, &s_panel));
    ESP_ERROR_CHECK(esp_lcd_panel_reset(s_panel));
    ESP_ERROR_CHECK(esp_lcd_panel_init(s_panel));
    ESP_ERROR_CHECK(esp_lcd_panel_invert_color(s_panel, true));
    ESP_ERROR_CHECK(esp_lcd_panel_set_gap(s_panel, LCD_COL_GAP, 0));
    ESP_ERROR_CHECK(esp_lcd_panel_mirror(s_panel, false, false));
    ESP_ERROR_CHECK(esp_lcd_panel_disp_on_off(s_panel, true));

    /* Backlight -- brightness from CONFIG_TC_SCREEN_BRIGHTNESS (percent) */
    const ledc_timer_config_t ledc_timer = {
        .speed_mode      = BL_LEDC_MODE,
        .timer_num       = BL_LEDC_TIMER,
        .duty_resolution = BL_LEDC_DUTY_RES,
        .freq_hz         = BL_LEDC_FREQ_HZ,
        .clk_cfg         = LEDC_AUTO_CLK,
    };
    ESP_ERROR_CHECK(ledc_timer_config(&ledc_timer));

    s_bl_max_duty = (1u << BL_LEDC_DUTY_RES) - 1u;
    const uint32_t bl_duty =
        (s_bl_max_duty * (uint32_t)CONFIG_TC_SCREEN_BRIGHTNESS) / 100u;

    const ledc_channel_config_t ledc_ch = {
        .speed_mode = BL_LEDC_MODE,
        .channel    = BL_LEDC_CH,
        .timer_sel  = BL_LEDC_TIMER,
        .intr_type  = LEDC_INTR_DISABLE,
        .gpio_num   = LCD_BL,
        .duty       = bl_duty,
        .hpoint     = 0,
    };
    ESP_ERROR_CHECK(ledc_channel_config(&ledc_ch));
}

/* Drive the backlight PWM to `percent` (0..100) of full brightness.
 * Used both for the initial CONFIG_TC_SCREEN_BRIGHTNESS setting and
 * by the screen-saver to blank / restore the panel. */
static void bl_set_percent(int percent)
{
    if (percent < 0) percent = 0;
    if (percent > 100) percent = 100;
    uint32_t duty = (s_bl_max_duty * (uint32_t)percent) / 100u;
    ledc_set_duty(BL_LEDC_MODE, BL_LEDC_CH, duty);
    ledc_update_duty(BL_LEDC_MODE, BL_LEDC_CH);
}

/* ---------------------------------------------------------------------
 * Screen saver: after CONFIG_TC_SCREENSAVER_TIMEOUT_S of touch/button
 * inactivity, turn the backlight off; any touch or button activity
 * restores it to CONFIG_TC_SCREEN_BRIGHTNESS. A timeout of 0 disables
 * the screen saver entirely.
 * --------------------------------------------------------------------- */
#if CONFIG_TC_SCREENSAVER_TIMEOUT_S > 0
static uint32_t s_last_activity_ms;
static bool     s_screen_off;

static void screensaver_wake(uint32_t now)
{
    s_last_activity_ms = now;
    if (s_screen_off) {
        bl_set_percent(CONFIG_TC_SCREEN_BRIGHTNESS);
        s_screen_off = false;
    }
}

static void screensaver_tick(uint32_t now)
{
    if (s_screen_off) return;
    uint32_t timeout_ms = (uint32_t)CONFIG_TC_SCREENSAVER_TIMEOUT_S * 1000u;
    if (now - s_last_activity_ms >= timeout_ms) {
        bl_set_percent(0);
        s_screen_off = true;
    }
}
#else
static inline void screensaver_wake(uint32_t now) { (void)now; }
static inline void screensaver_tick(uint32_t now) { (void)now; }
#endif
#endif /* CONFIG_TC_HAS_DISPLAY */

#if CONFIG_TC_HAS_TOUCH
static void hw_touch_init(void)
{
    /* I2C master bus */
    i2c_master_bus_handle_t i2c_bus;
    const i2c_master_bus_config_t i2c_cfg = {
        .clk_source                   = I2C_CLK_SRC_DEFAULT,
        .i2c_port                     = I2C_NUM_0,
        .scl_io_num                   = TP_SCL,
        .sda_io_num                   = TP_SDA,
        .glitch_ignore_cnt            = 7,
        .flags.enable_internal_pullup = true,
    };
    ESP_ERROR_CHECK(i2c_new_master_bus(&i2c_cfg, &i2c_bus));

    /* Add AXS5106 device */
    i2c_master_dev_handle_t dev;
    const i2c_device_config_t dev_cfg = {
        .dev_addr_length = I2C_ADDR_BIT_LEN_7,
        .device_address  = ESP_LCD_TOUCH_IO_I2C_AXS5106_ADDRESS,
        .scl_speed_hz    = 400000,
    };
    ESP_ERROR_CHECK(i2c_master_bus_add_device(i2c_bus, &dev_cfg, &dev));

    /* Touch configuration for portrait rotation 0:
     *   mirror_x=1 maps raw x so that x=0 is at the left edge on screen. */
    const esp_lcd_touch_config_t tp_cfg = {
        .x_max        = LCD_H_RES,
        .y_max        = LCD_V_RES,
        .rst_gpio_num = TP_RST,
        .int_gpio_num = TP_INT,
        .levels = {
            .reset     = 0,
            .interrupt = 0,
        },
        .flags = {
            .swap_xy  = 0,
            .mirror_x = 1,
            .mirror_y = 0,
        },
    };

    /* Retry -- controller may be slow to wake after power-on. */
    for (int attempt = 1; attempt <= 6; attempt++) {
        esp_err_t err = esp_lcd_touch_new_i2c_axs5106(dev, &tp_cfg, &s_touch);
        if (err == ESP_OK) {
            ESP_LOGI(TAG, "AXS5106 ready (attempt %d)", attempt);
            return;
        }
        ESP_LOGW(TAG, "AXS5106 attempt %d: %s", attempt, esp_err_to_name(err));
        vTaskDelay(pdMS_TO_TICKS(80));
    }
    s_touch = NULL;
    ESP_LOGW(TAG, "Touch unavailable -- gesture input disabled");
}
#endif /* CONFIG_TC_HAS_TOUCH */

/* Configure the button (and, on touch boards, mode) GPIOs as pull-up
 * inputs. */
static void hw_buttons_init(void)
{
    uint64_t pin_mask = 0;
    for (int i = 0; i < BTN_GPIO_COUNT; i++) {
        if (s_btn_gpios[i] >= 0) {
            pin_mask |= 1ULL << s_btn_gpios[i];
        }
    }
#if CONFIG_TC_HAS_TOUCH
    pin_mask |= 1ULL << MODE_GPIO;
#endif

    const gpio_config_t cfg = {
        .pin_bit_mask = pin_mask,
        .mode         = GPIO_MODE_INPUT,
        .pull_up_en   = GPIO_PULLUP_ENABLE,
        .pull_down_en = GPIO_PULLDOWN_DISABLE,
        .intr_type    = GPIO_INTR_DISABLE,
    };
    ESP_ERROR_CHECK(gpio_config(&cfg));

    char btn_list[160];
    int  pos = 0;
    for (int i = 0; i < BTN_GPIO_COUNT; i++) {
        int remaining = (int)sizeof(btn_list) - pos;
        if (remaining <= 0) {
            break;
        }
        int n;
        if (s_btn_gpios[i] >= 0) {
            n = snprintf(btn_list + pos, (size_t)remaining,
                         "%s%d", (i == 0) ? "" : ",", s_btn_gpios[i]);
        } else {
            n = snprintf(btn_list + pos, (size_t)remaining,
                         "%soff", (i == 0) ? "" : ",");
        }
        if (n < 0 || n >= remaining) {
            break;  /* encoding error or output truncated */
        }
        pos += n;
    }
#if CONFIG_TC_HAS_TOUCH
    ESP_LOGI(TAG, "Buttons 0-15 GPIO %s  mode GPIO %d", btn_list, MODE_GPIO);
#else
    ESP_LOGI(TAG, "Buttons 0-15 GPIO %s", btn_list);
#endif
}

/* ---------------------------------------------------------------------
 * Vibration motor haptic feedback
 *
 * A dedicated task drains a queue of vibration patterns so the event
 * producers (touch task) never block on the motor timing.  Each pattern
 * pulses the motor GPIO "count" times for "on_ms" milliseconds, with an
 * idle "gap_ms" between consecutive pulses.
 * --------------------------------------------------------------------- */
#if CONFIG_TC_HAS_VIBRATION
typedef struct {
    uint16_t on_ms;
    uint16_t gap_ms;
    uint8_t  count;
} vib_pattern_t;

static QueueHandle_t s_vib_queue;

/* Queue a vibration pattern; drops silently if the queue is full or the
 * subsystem has not been initialised yet. */
static void vibration_trigger(uint16_t on_ms, uint16_t gap_ms, uint8_t count)
{
    if (!s_vib_queue) {
        return;
    }
    vib_pattern_t p = { .on_ms = on_ms, .gap_ms = gap_ms, .count = count };
    xQueueSend(s_vib_queue, &p, 0);
}

static void vibration_task(void *arg)
{
    (void)arg;
    vib_pattern_t p;
    while (1) {
        if (xQueueReceive(s_vib_queue, &p, portMAX_DELAY) != pdTRUE) {
            continue;
        }
        for (uint8_t i = 0; i < p.count; i++) {
            gpio_set_level(VIB_GPIO, 1);
            vTaskDelay(pdMS_TO_TICKS(p.on_ms));
            gpio_set_level(VIB_GPIO, 0);
            if (i + 1 < p.count) {
                vTaskDelay(pdMS_TO_TICKS(p.gap_ms));
            }
        }
    }
}

/* Configure the vibration motor GPIO as an output (driven low) and start
 * the vibration task. */
static void hw_vibration_init(void)
{
    const gpio_config_t cfg = {
        .pin_bit_mask = 1ULL << VIB_GPIO,
        .mode         = GPIO_MODE_OUTPUT,
        .pull_up_en   = GPIO_PULLUP_DISABLE,
        .pull_down_en = GPIO_PULLDOWN_DISABLE,
        .intr_type    = GPIO_INTR_DISABLE,
    };
    ESP_ERROR_CHECK(gpio_config(&cfg));
    gpio_set_level(VIB_GPIO, 0);

    s_vib_queue = xQueueCreate(8, sizeof(vib_pattern_t));
    ESP_ERROR_CHECK(s_vib_queue ? ESP_OK : ESP_ERR_NO_MEM);
    BaseType_t task_ok =
        xTaskCreate(vibration_task, "vibration", 2048, NULL, 4, NULL);
    ESP_ERROR_CHECK(task_ok == pdPASS ? ESP_OK : ESP_ERR_NO_MEM);
    ESP_LOGI(TAG, "Vibration motor GPIO %d", VIB_GPIO);
}
#else
static inline void vibration_trigger(uint16_t on_ms, uint16_t gap_ms,
                                     uint8_t count)
{
    (void)on_ms;
    (void)gap_ms;
    (void)count;
}
#endif /* CONFIG_TC_HAS_VIBRATION */
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
void app_main(void)
{
    ESP_LOGI(TAG, "ESP32 Touch Controller starting");

#if CONFIG_TC_HAS_DISPLAY
    hw_lcd_init();
#endif
#if CONFIG_TC_HAS_TOUCH
    hw_touch_init();
#endif
    hw_buttons_init();
#if CONFIG_TC_HAS_VIBRATION
    hw_vibration_init();
#endif

#if CONFIG_TC_HAS_DISPLAY
    lvgl_setup();

    /* Build UI inside the LVGL lock (-1 = wait indefinitely until LVGL task
     * gives up the mutex, which it does during its sleep phase).           */
    if (lvgl_port_lock(-1)) {
        ui_create();
        lvgl_port_unlock();
    }
#endif

    ESP_ERROR_CHECK(uart_gamepad_init());

#if CONFIG_TC_HAS_TOUCH
    xTaskCreate(touch_task, "touch", 4096, NULL, 5, NULL);
    ESP_LOGI(TAG, "Running -- initial mode: VERTICAL");
#else
    xTaskCreate(button_task, "button", 4096, NULL, 5, NULL);
    ESP_LOGI(TAG, "Running -- buttons only (no display/touch)");
#endif
}

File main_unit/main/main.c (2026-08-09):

/*
 * esp32-smart-keyboard / main
 *
 * Boot sequence:
 *   1. nvs_flash_init()        -- needed by BLE bonding + UI prefs
 *   2. board_init()            -- panel reset, capability surface
 *   3. display_init()          -- framebuffer + ILI9341 SPI driver
 *   4. Splash screen
 *   5. keyboard_ui_init()      -- UI state, NVS-persisted prefs
 *   6. keyboard_ui_redraw_now()-- paint the virtual keyboard NOW,
 *                                 so the user sees it before the
 *                                 (potentially slow) HID / gamepad
 *                                 bring-up begins
 *   7. hid_init()              -- BLE (NimBLE) or USB (TinyUSB), per
 *                                 CONFIG_SK_HID_TRANSPORT_*
 *   8. narrator_init()         -- audio backend if available
 *   9. gamepad_uart_start()   -- receive-only UART HID link
 *  10. input_router_start()
 *  11. keyboard_ui_start_task()-- async redraw pump for subsequent
 *                                 state changes
 */

#include <stdio.h>

#include <esp_log.h>
#include <esp_err.h>
#include <nvs_flash.h>
#include <freertos/FreeRTOS.h>
#include <freertos/task.h>

#include "board.h"
#include "display.h"
#include "theme.h"
#include "fonts.h"
#include "kb_layout.h"
#include "keyboard_ui.h"
#include "gamepad_uart.h"
#include "input_router.h"
#include "hid.h"
#include "narrator.h"
#include "audio.h"

static const char *TAG = "main";

#define FW_VERSION "0.1.0-dev"

static void splash(void)
{
    const theme_t *th = theme_active();
    int w = display_width();
    int h = display_height();
    display_clear(th->win_bg);

    const board_t *b = board_get();
    const char *line1 = "SmartKeyboard";
    char        line2[40];
    char        line3[40];
    snprintf(line2, sizeof(line2), "fw %s", FW_VERSION);
    snprintf(line3, sizeof(line3), "%s: starting", hid_transport_name());

    int s = 3;  /* 3x = 24-px tall text */
    int gw = 8 * s;
    int y = (h - 3 * gw - 2 * 6) / 2;

    int l1x = (w - (int)strlen(line1) * gw) / 2;
    int l2x = (w - (int)strlen(line2) * 8) / 2;
    int l3x = (w - (int)strlen(line3) * 8) / 2;

    display_draw_string(l1x, y,                line1, s, th->key_label, th->win_bg, true);
    display_draw_string(l2x, y + gw + 8,        line2, 1, th->status_ind_fg, th->win_bg, true);
    display_draw_string(l3x, y + gw + 8 + 16,   line3, 1, th->status_ind_fg, th->win_bg, true);

    /* Board name as a tiny footer. */
    int len = (int)strlen(b->name);
    display_draw_string((w - len * 8) / 2, h - 12, b->name, 1,
                        th->status_ind_fg, th->win_bg, true);
    display_flush();
}

static void on_hid_status(const char *text, bool connected)
{
    ESP_LOGI(TAG, "%s", text);
    keyboard_ui_set_hid_status(text, connected);
}

void app_main(void)
{
    /* 1. NVS. */
    esp_err_t err = nvs_flash_init();
    if (err == ESP_ERR_NVS_NO_FREE_PAGES || err == ESP_ERR_NVS_NEW_VERSION_FOUND) {
        ESP_ERROR_CHECK(nvs_flash_erase());
        err = nvs_flash_init();
    }
    ESP_ERROR_CHECK(err);

    /* 2. Board + display. */
    board_init();
    display_init();
    display_set_backlight(CONFIG_SK_DISPLAY_BACKLIGHT_PERCENT);

    /* 3. Splash. */
    splash();
    vTaskDelay(pdMS_TO_TICKS(1200));

    /* 4. UI state + initial paint of the virtual keyboard.
     *
     * We deliberately render the keyboard SYNCHRONOUSLY here, BEFORE
     * starting HID and gamepad, so the user sees a visible UI even
     * if those subsystems take noticeable time to come up (BLE
     * advertising, USB enumeration, gamepad UART bring-up can
     * each take noticeable time, and a hung peripheral would
     * otherwise leave the panel showing only the splash). The async
     * redraw task is started afterwards to handle subsequent state
     * changes. */
    keyboard_ui_init();
    keyboard_ui_redraw_now();

    /* 5. HID transport (BLE or USB, per Kconfig). */
    hid_init(on_hid_status);

    /* 6. Audio + narrator (no-ops on boards without speaker).
     *    Immediately after bring-up, play a short procedural
     *    chime so the user can hear that the speaker path is
     *    operational without waiting for the first narrated
     *    keystroke. Stubbed on boards without a speaker. */
    narrator_init();
    audio_play_startup_tune();

    /* 7. Gamepad + router. */
    QueueHandle_t q = gamepad_uart_start();
    input_router_start(q);

    /* 8. Async UI redraw pump for state changes driven by HID
     * status callbacks and gamepad input. */
    keyboard_ui_start_task();

    ESP_LOGI(TAG, "boot complete; firmware %s on %s",
             FW_VERSION, board_get()->name);
}

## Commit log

2026-08-09 moved main unit and input controller into a monorepo
    [body_bottom.FCStd, body_top.FCStd, partitions.csv]
2026-08-09 Add USB VID/PID and screensaver for main unit + touch controller
2026-08-09 Wire shifted number-row symbols into narrator
2026-08-09 Increase factory/storage partition sizes for 16MB flash
    [partitions.csv]
2026-08-09 moved 3D_Prints/ to the root
    [body_bottom.FCStd, body_top.FCStd]
2026-08-10 3D_Prints: screen elevation, firmware flash hole
    [body_bottom-Body.3mf, body_bottom.FCStd, body_top-Body.3mf]
2026-08-25 Added schematics
    [smart_inclusive_keyboard.kicad_pcb, smart_inclusive_keyboard.kicad_sch]
2026-08-27 BOM, Images, README update
